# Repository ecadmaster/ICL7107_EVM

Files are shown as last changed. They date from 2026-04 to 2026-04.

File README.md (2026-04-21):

# ICL7107 Evaluation Module (EVM)

ecl7107-3d

Este repositorio contiene el diseño de hardware de una tarjeta de evaluación para el ICL7107, un convertidor analógico-digital (ADC) de 3.5 dígitos diseñado para controlar displays LED. Este proyecto se desarrolla como material de práctica para la asignatura Laboratorio de Electrónica II de la Universidad de Los Andes (ULA).

## Descripción del Proyecto

El ICL7107 es un circuito integrado ampliamente utilizado en la instrumentación electrónica, específicamente en la construcción de voltímetros y multímetros digitales. Esta placa permite a los estudiantes y entusiastas experimentar con el acondicionamiento de señales y la visualización de datos sin necesidad de realizar el cableado complejo en protoboard.

## Características Técnicas

- Conversor: ICL7107 (ADC Dual-Slope).
- Visualización: 3.5 dígitos para displays de siete segmentos (ánodo común).
- Alimentación: $$+5VDC$$ vía microUSB, internamente contiene circuito inversor para el $$-5VDC$$.
- Ajustes: Potenciómetro de precisión para calibración de voltaje de referencia.
- Software de Diseño: [KiCad EDA](https://www.kicad.org/)  9.0 (o superior).

## Esquema del Circuito

A continuación, se presenta el diagrama esquemático del sistema:

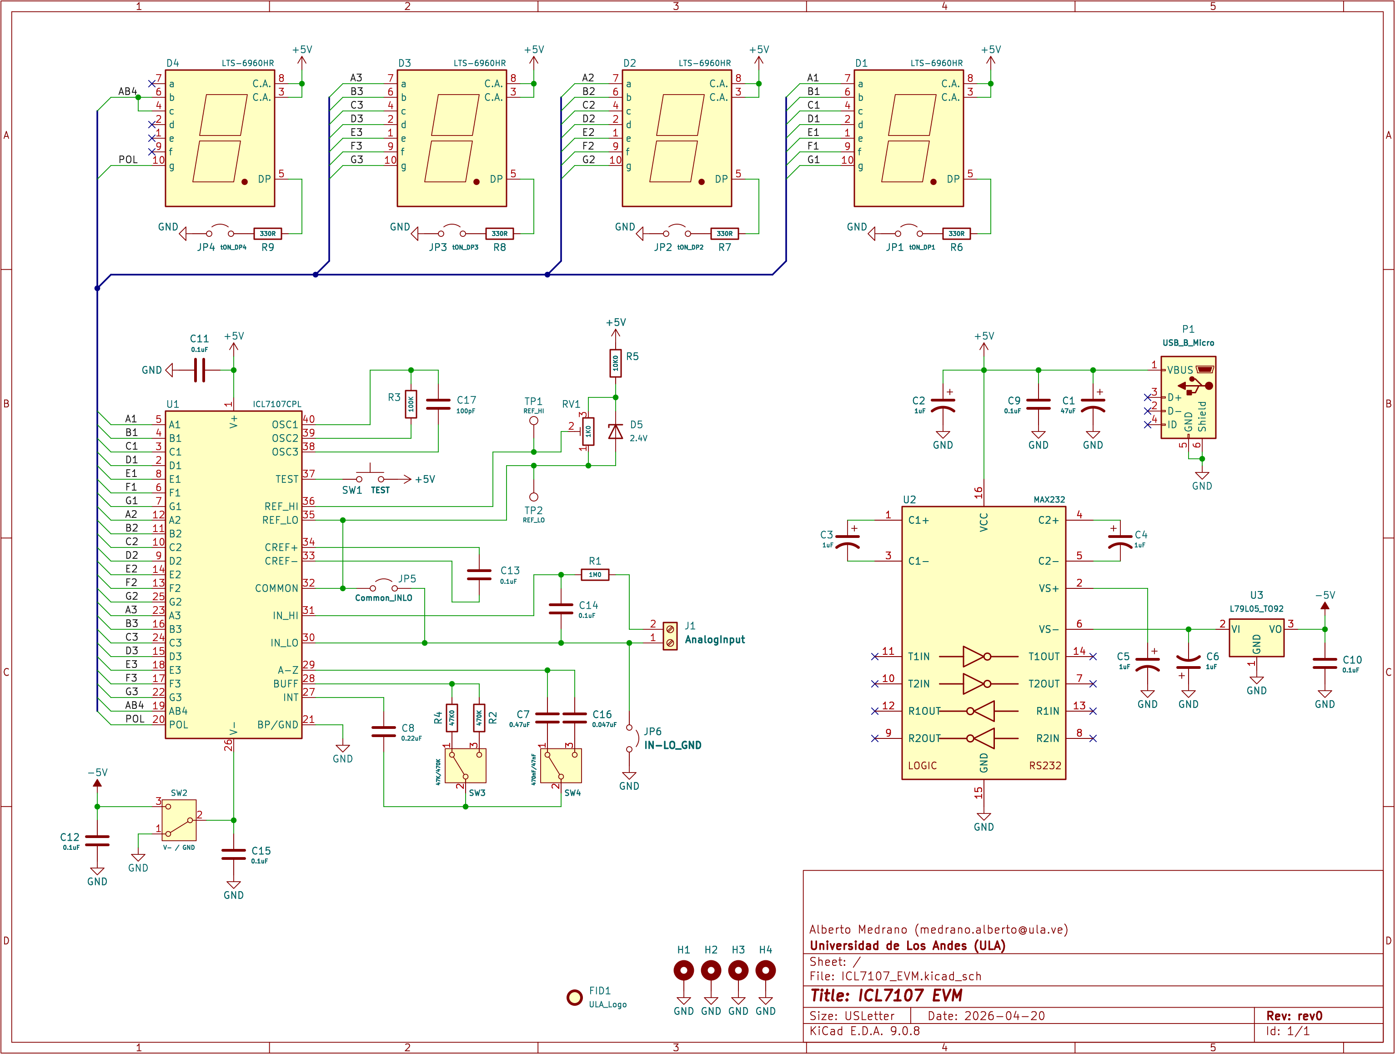
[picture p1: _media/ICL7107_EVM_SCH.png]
ecl7107-sch


## Lista de Materiales (BOM)

Para ensamblar este módulo, se requieren los siguientes componentes:

| Cantidad | Referencia | Descripción |
| :--- | :--- | :--- |
| 1	| C1 | Capacitor Electrolítico 47uF/16V |
| 5	| C2-6 | Capacitor Electrolítico 1uF/25V |
| 1	| C7 | Capacitor Cerámico 0.47uF |
| 1	| C8 | Capacitor Cerámico 0.22uF |
| 7	| C9-15 | Capacitor Cerámico 0.1uF |
| 1	| C16 | Capacitor Cerámico 0.047uF |
| 1	| C17 | Capacitor Cerámico 100pF |
| 4	| D1-4 | Display 7 segmentos, ánodo común |
| 1	| D5 | Diodo Zener 2.4V |
| 1	| J1 | Bornera 2 pines |
| 1	| JP1-6 | 1x02 Pin header con jumpers |
| 1	| P1 | Conector microUSB |
| 1	| R1 | Resistencia 1/4W 1 M ohm |
| 1	| R2 | Resistencia 1/4W 470k ohm |
| 1	| R3 | Resistencia 1/4W 100k ohm |
| 1	| R4 | Resistencia 1/4W 47k ohm |
| 1	| R5 | Resistencia 1/4W 10k ohm |
| 4	| R6-9 | Resistencia 1/4W 330 ohm |
| 1	| RV1 | Potenciómetro Trimmer 1k ohm |
| 1	| SW1 | Pulsador 6mm |
| 3	| SW2-4 | Switch, CuK OS102011MA1QN1 o similar |
| 1	| TP1-2 | Punta de prueba, Keystone 5010 o similar |
| 1	| U1 | Base de 40 pines + ICL7107 |
| 1	| U2 | Base de 16 pines + MAX232 |
| 1	| U3 | Regulador LM7905 |

Nota 1: La lista completa detallada se encuentra en el archivo ICL7107_EVM_BOM.csv

Nota 2: Se recomienda colocar 8x sockets de 1x05 pines hembra para la instalación de los display 7-segmento, de modo que pueda removerlos fácilmente de ser necesario.

## Instalación y Uso

Clona el repositorio:

```git clone https://github.com/ecadmaster/ICL7107_EVM.git```

Abre el archivo .kicad_pro con KiCad para revisar el PCB o generar los archivos Gerber para fabricación.

Consulta la datasheet para entender los límites operativos del integrado.

## Contribuciones y Licencia
Este proyecto está bajo la licencia MIT. Las sugerencias de mejora para el entorno académico de la Escuela de Ingeniería Eléctrica son bienvenidas.

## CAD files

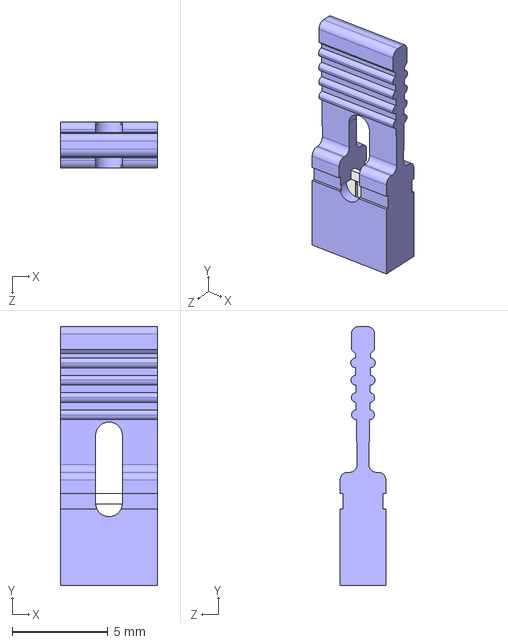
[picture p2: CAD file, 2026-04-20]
_local/KOBICONN_151-8031.step
5.05 x 13.5 x 2.39 mm

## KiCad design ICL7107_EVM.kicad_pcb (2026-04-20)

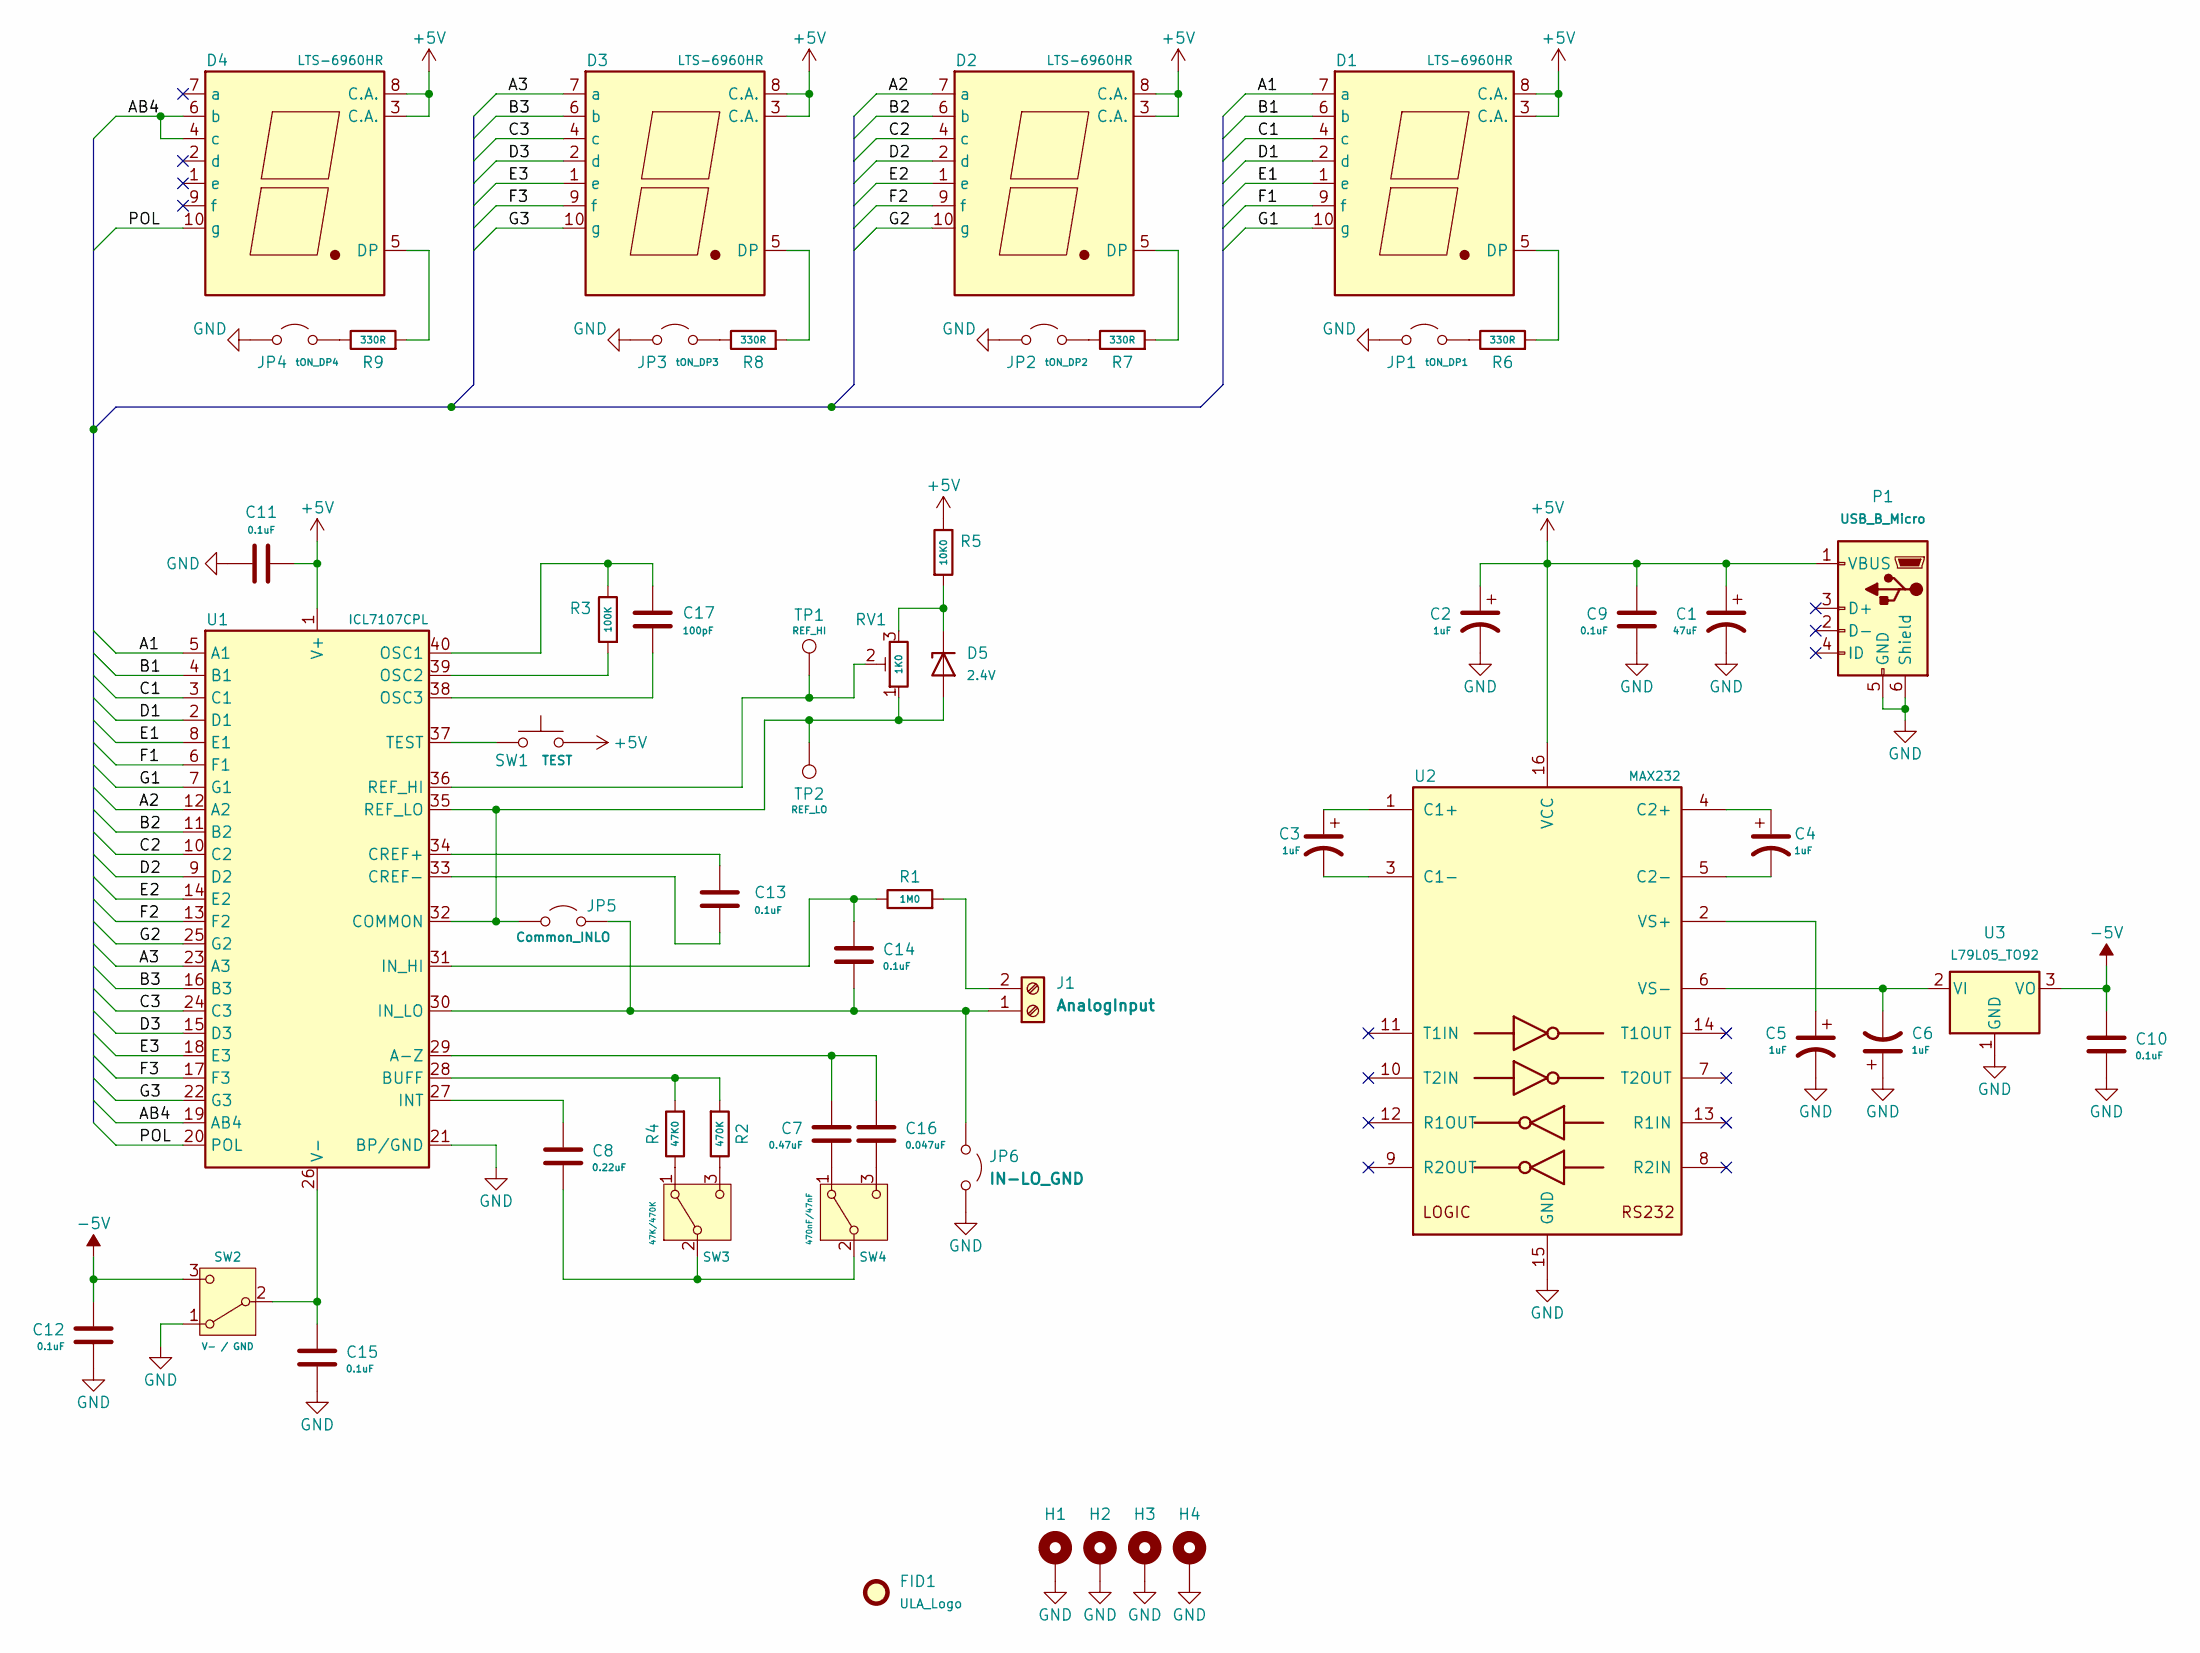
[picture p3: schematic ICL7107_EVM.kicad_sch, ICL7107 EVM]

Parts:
C1: 47uF; CP_Radial_D6.3mm_P2.50mm
C2, C3, C4, C5, C6: 1uF; CP_Radial_D5.0mm_P2.50mm
C7: 0.47uF; C_Disc_D4.7mm_W2.5mm_P5.00mm
C8: 0.22uF; C_Disc_D4.7mm_W2.5mm_P5.00mm
C9, C10, C11, C12, C13, C14, C15: 0.1uF; C_Disc_D4.7mm_W2.5mm_P5.00mm
C16: 0.047uF; C_Disc_D4.7mm_W2.5mm_P5.00mm
C17: 100pF; C_Disc_D4.7mm_W2.5mm_P5.00mm
D1, D2, D3, D4: LTS-6960HR; 7SegmentLED_LTS6760_LTS6780
D5: 2.4V; D_DO-35_SOD27_P7.62mm_Horizontal
FID1: ULA_Logo; ULA-Logo_9x12mm_SilkS
H1, H2, H3, H4: MountingHole_Pad; MountingHole_3.2mm_M3_Pad_Via
J1: AnalogInput; TerminalBlock_Phoenix_MKDS-1,5-2-5.08_1x02_P5.08mm_Horizont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
JP1: tON_DP1; PinHeader_1x02_P2.54mm_Vertical
JP2: tON_DP2; PinHeader_1x02_P2.54mm_Vertical
JP3: tON_DP3; PinHeader_1x02_P2.54mm_Vertical
JP4: tON_DP4; PinHeader_1x02_P2.54mm_Vertical
JP5: Common_INLO; PinHeader_1x02_P2.54mm_Vertical
JP6: IN-LO_GND; PinHeader_1x02_P2.54mm_Vertical
P1: USB_B_Micro; USB_Micro-B_Molex_47346-0001
R1: 1M0; R_Axial_DIN0204_L3.6mm_D1.6mm_P7.62mm_Horizontal
R2: 470K; R_Axial_DIN0204_L3.6mm_D1.6mm_P7.62mm_Horizontal
R3: 100K; R_Axial_DIN0204_L3.6mm_D1.6mm_P7.62mm_Horizontal
R4: 47K0; R_Axial_DIN0204_L3.6mm_D1.6mm_P7.62mm_Horizontal
R5: 10K0; R_Axial_DIN0204_L3.6mm_D1.6mm_P7.62mm_Horizontal
R6, R7, R8, R9: 330R; R_Axial_DIN0204_L3.6mm_D1.6mm_P7.62mm_Horizontal
RV1: 1K0; Potentiometer_Bourns_3299W_Vertical
SW1: TEST; SW_PUSH_6mm
SW2: V- / GND; SW_Slide_SPDT_Angled_CK_OS102011MA1Q
SW3: 47K/470K; SW_Slide_SPDT_Angled_CK_OS102011MA1Q
SW4: 470nF/47nF; SW_Slide_SPDT_Angled_CK_OS102011MA1Q
TP1: REF_HI; TestPoint_Keystone_5005-5009_Compact
TP2: REF_LO; TestPoint_Keystone_5005-5009_Compact
U1: ICL7107CPL; DIP-40_W15.24mm_Socket_LongPads
U2: MAX232; DIP-16_W7.62mm_Socket_LongPads
U3: L79L05_TO92; TO-92

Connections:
+5V: C1.1, C2.1, C9.1, C11.1, D1.3 (C.A.), D1.8 (C.A.), D2.3 (C.A.), D2.8 (C.A.), D3.3 (C.A.), D3.8 (C.A.), D4.3 (C.A.), D4.8 (C.A.), P1.1 (VBUS), R5.1, SW1.2, U1.1 (V+), U2.16 (VCC)
-5V: C10.1, C12.1, SW2.3 (C), U3.3 (VO)
/A1: D1.7 (a), U1.5 (A1)
/A2: D2.7 (a), U1.12 (A2)
/A3: D3.7 (a), U1.23 (A3)
/AB4: D4.4 (c), D4.6 (b), U1.19 (AB4)
/B1: D1.6 (b), U1.4 (B1)
/B2: D2.6 (b), U1.11 (B2)
/B3: D3.6 (b), U1.16 (B3)
/C1: D1.4 (c), U1.3 (C1)
/C2: D2.4 (c), U1.10 (C2)
/C3: D3.4 (c), U1.24 (C3)
/D1: D1.2 (d), U1.2 (D1)
/D2: D2.2 (d), U1.9 (D2)
/D3: D3.2 (d), U1.15 (D3)
/E1: D1.1 (e), U1.8 (E1)
/E2: D2.1 (e), U1.14 (E2)
/E3: D3.1 (e), U1.18 (E3)
/F1: D1.9 (f), U1.6 (F1)
/F2: D2.9 (f), U1.13 (F2)
/F3: D3.9 (f), U1.17 (F3)
/G1: D1.10 (g), U1.7 (G1)
/G2: D2.10 (g), U1.25 (G2)
/G3: D3.10 (g), U1.22 (G3)
/POL: D4.10 (g), U1.20 (POL)
GND: C1.2, C2.2, C5.2, C6.1, C9.2, C10.2, C11.2, C12.2, C15.2, H1.1, H2.1, H3.1, H4.1, JP1.1 (A), JP2.1 (A), JP3.1 (A), JP4.1 (A), JP6.2 (B), P1.5 (GND), P1.6 (Shield), SW2.1 (A), U1.21 (BP/GND), U2.15 (GND), U3.1 (GND)
unnamed: D1.5 (DP), R6.2
unnamed: D2.5 (DP), R7.2
unnamed: D3.5 (DP), R8.2
unnamed: D4.5 (DP), R9.2
unnamed: D5.2 (A), JP5.2 (B), RV1.1, TP2.1, U1.32 (COMMON), U1.35 (REF_LO)
unnamed: D5.1 (K), R5.2, RV1.3
unnamed: C14.2, J1.1, JP5.1 (A), JP6.1 (A), U1.30 (IN_LO)
unnamed: J1.2, R1.2
unnamed: JP1.2 (B), R6.1
unnamed: JP2.2 (B), R7.1
unnamed: JP3.2 (B), R8.1
unnamed: JP4.2 (B), R9.1
unnamed: C15.1, SW2.2 (B), U1.26 (V-)
unnamed: R4.1, SW3.1 (A)
unnamed: C8.2, SW3.2 (B), SW4.2 (B)
unnamed: R2.1, SW3.3 (C)
unnamed: C7.2, SW4.1 (A)
unnamed: C16.2, SW4.3 (C)
unnamed: C7.1, C16.1, U1.29 (A-Z)
unnamed: R2.2, R4.2, U1.28 (BUFF)
unnamed: C13.1, U1.34 (CREF+)
unnamed: C13.2, U1.33 (CREF-)
unnamed: C8.1, U1.27 (INT)
unnamed: C14.1, R1.1, U1.31 (IN_HI)
unnamed: C17.2, R3.1, U1.40 (OSC1)
unnamed: R3.2, U1.39 (OSC2)
unnamed: C17.1, U1.38 (OSC3)
unnamed: RV1.2, TP1.1, U1.36 (REF_HI)
unnamed: SW1.1, U1.37 (TEST)
unnamed: C3.1, U2.1 (C1+)
unnamed: C3.2, U2.3 (C1-)
unnamed: C4.1, U2.4 (C2+)
unnamed: C4.2, U2.5 (C2-)
unnamed: C5.1, U2.2 (VS+)
unnamed: C6.2, U2.6 (VS-), U3.2 (VI)

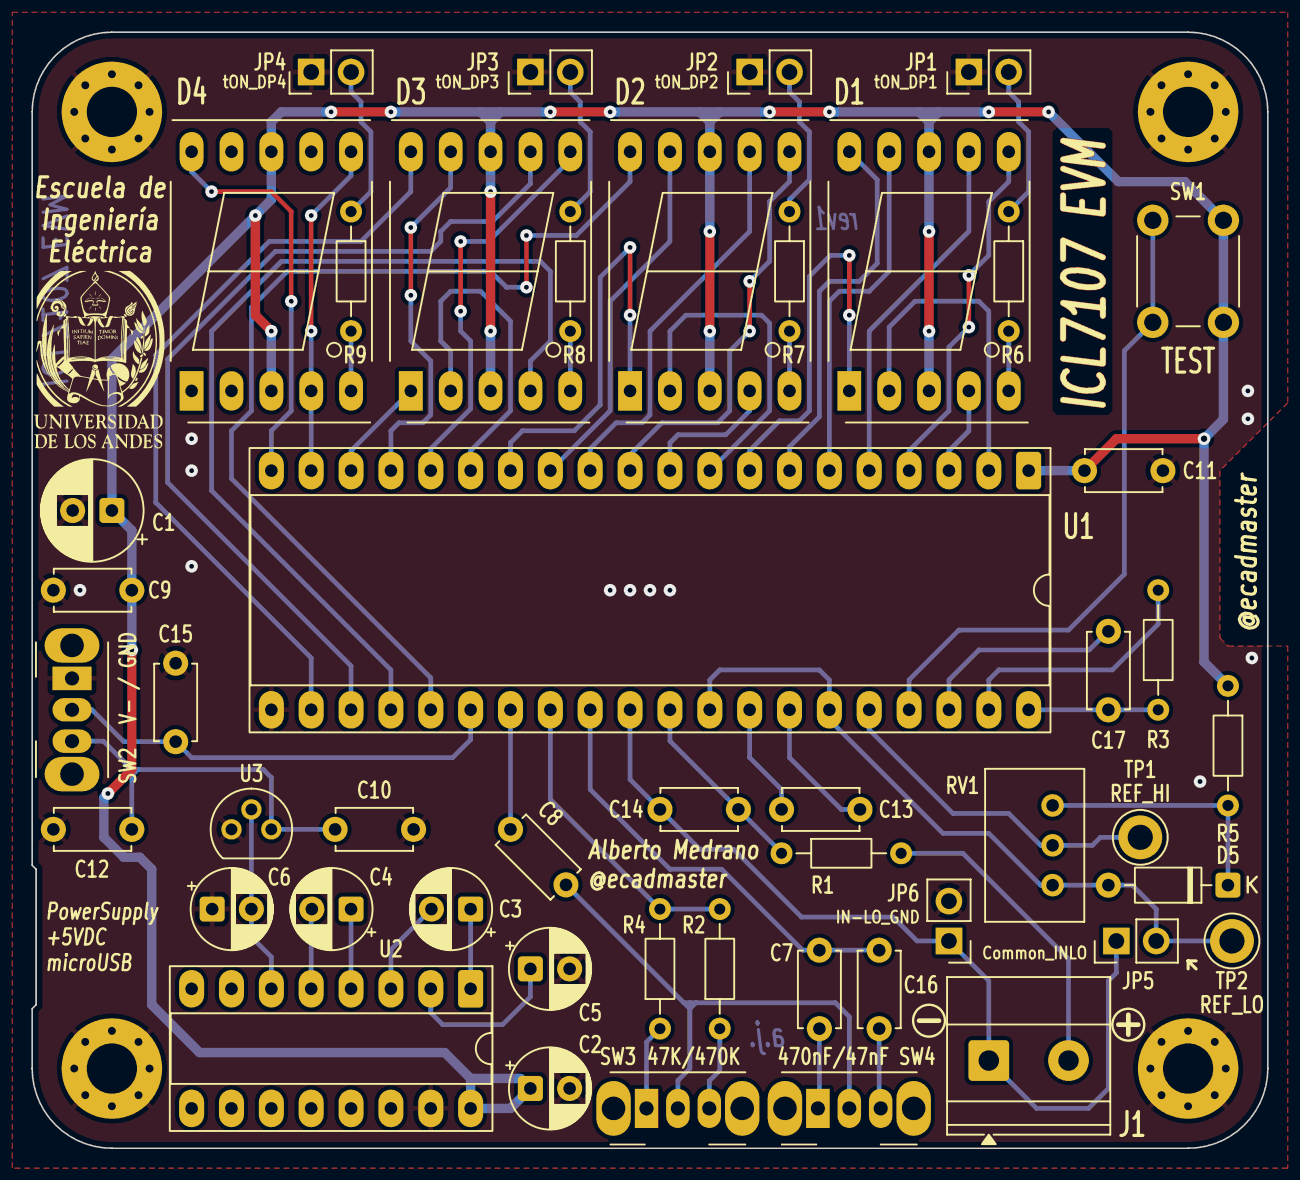
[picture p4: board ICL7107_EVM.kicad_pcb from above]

Board: 2 copper layers, 78.7 x 71.1 mm, 54 parts (1 on the bottom side), 61 nets.

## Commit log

2026-04-20 agregando fuentes iniciales
    [ICL7107_EVM-B_Cu.gbr, ICL7107_EVM-B_Mask.gbr, ICL7107_EVM-B_Silkscreen.gbr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]
2026-10-17 Add badges for MIT license and KiCad
    Added badges for license and KiCad in README.
